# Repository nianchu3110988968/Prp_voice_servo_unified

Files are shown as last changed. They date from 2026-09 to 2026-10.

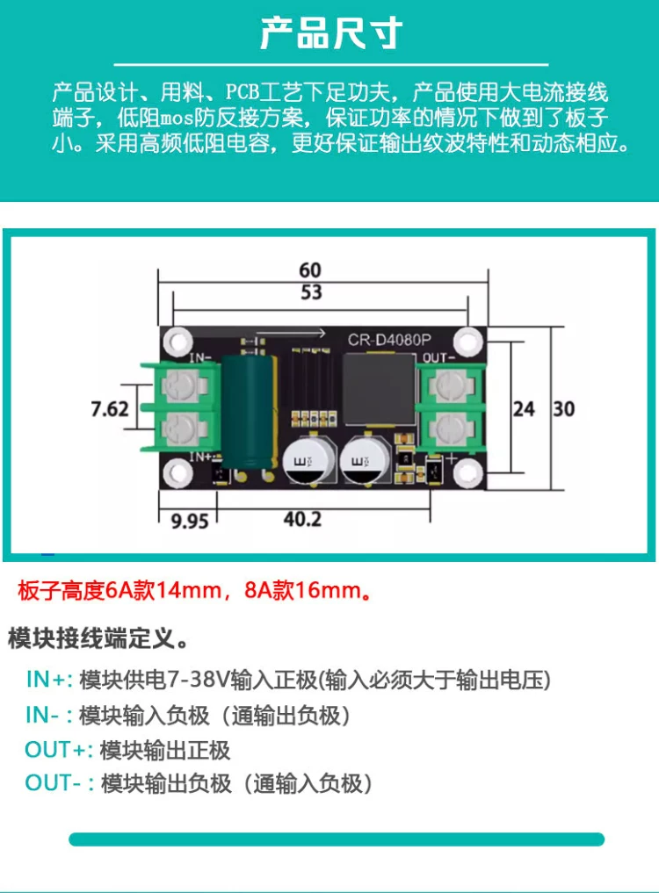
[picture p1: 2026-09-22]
硬件参数/降压板.webp

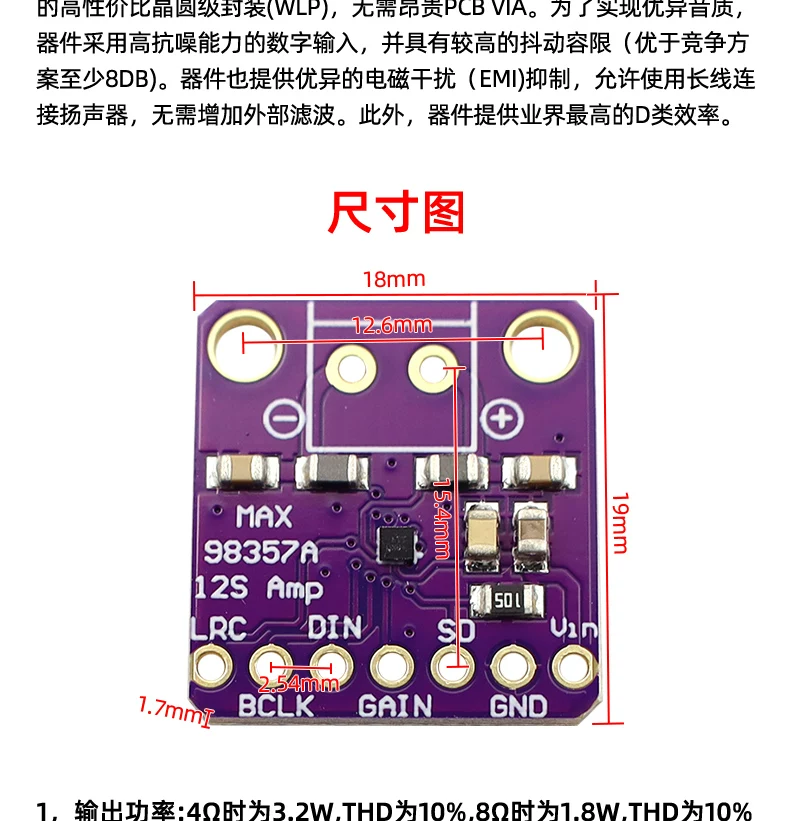
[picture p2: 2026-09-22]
硬件参数/MAX98357.webp

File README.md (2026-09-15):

# 🎤 ESP32-S3 智能语音助手 - 舵机控制版

## 当前统一工程入口（2026-09-15）

本地三处项目已集中到本根目录：导航见`项目入口.md`，编辑器入口`PRP.code-workspace`。原`E:\Projects2026\Prp`已迁入`legacy/Prp_servo_arduino`，原`E:\college\毛绒治愈机器人PRP`已迁入`archive/PRP_原始项目资料`。旧资料完整保留，不混入现行源码；归档暂不上传Git。

当前进度以`docs/README.md`、`docs/工作留档/task_progress.md`和`docs/项目指南/project_structure_map.md`为准；下方早期示例说明不代表最新实测状态。

私有仓库：`https://github.com/nianchu3110988968/Prp_voice_servo_unified`。每阶段验证后提交和推送；不提交Wi-Fi密码、真实录音、模型、生成日志或构建缓存。项目外GPT-SoVITS安装及其权重需另外保留，Git代码仓库不等于全电脑备份。

新克隆项目时，先创建本地网络配置（已有该文件时不要覆盖）：

```powershell
if (!(Test-Path .\main\network_config.h)) {
    Copy-Item .\main\network_config.example.h .\main\network_config.h
}
```

自行编辑`main/network_config.h`填写本机Wi-Fi与服务器地址后运行`platformio run`。配置模板不含真实凭据；编译不等于烧录。本轮分段延迟说明在`docs/项目指南/voice_latency_logging.md`。

> **智能语音控制舵机** | 支持语音唤醒、命令识别和舵机精确控制

**项目特色**：通过语音命令控制SG90舵机旋转，实现智能化的机械控制

## 🌟 本示例代码主要做了什么？

这是一个完整的智能语音助手实现，专门用于控制SG90舵机。当你说"你好小智"时，它会播放欢迎音频并进入命令模式。然后你可以说"帮我开灯"（舵机顺时针旋转90度）、"帮我关灯"（舵机逆时针旋转90度）等指令，系统会控制舵机旋转并播放确认音频。

**为什么做这个？**
舵机是机器人和自动化项目中的核心组件，通过语音控制舵机可以实现更智能的人机交互。这个项目展示了如何将语音识别技术与精确的PWM舵机控制相结合，为智能机器人、自动化设备等项目提供参考。

## ⚡ 功能特性

- ✅ **语音唤醒检测** - 支持"你好小智"唤醒词
- ✅ **命令词识别** - 支持"帮我开灯"、"帮我关灯"、"拜拜"等指令
- ✅ **音频反馈播放** - 每个操作都有对应的语音确认
- ✅ **SG90舵机控制** - 根据语音指令精确控制舵机角度
- ✅ **PWM精确控制** - 50Hz频率，0.5ms-2.5ms脉宽范围，支持0-180度
- ✅ **智能超时管理** - 5 秒无指令自动退出，支持连续指令
- ✅ **角度记忆功能** - 记住当前舵机位置，支持相对旋转

## 📦 需要准备什么？

### 硬件清单（淘宝都能买到）

| 部件 | 推荐型号 | 备注 |
| --- | --- | --- |
| 开发板 | ESP32-S3-DevKitC-1 | 必须是 S3 版本，需要 PSRAM |
| 麦克风 | INMP441 | 约 5 元/个 |
| 功放 | MAX98357A | 约 8 元/个 |
| 喇叭 | 4Ω 3W 小喇叭 | 约 3 元/个 |
| 舵机 | SG90 180度舵机 | 约 8 元/个，支持0-180度 |

### 接线图（舵机控制版）

```text
麦克风(INMP441) → ESP32开发板
-----------------------------
VDD（麦克风）→ 3.3V（开发板）  // 接电源正极
GND（麦克风）→ GND（开发板）   // 接电源负极
SD  （麦克风）→ GPIO6         // 数据线
WS  （麦克风）→ GPIO4         // 左右声道选择
SCK （麦克风）→ GPIO5         // 时钟线

功放(MAX98357A) → ESP32开发板
-----------------------------
VIN（功放）→ 3.3V（开发板）   // 接电源正极
GND（功放）→ GND（开发板）    // 接电源负极
DIN（功放）→ GPIO7           // 音频数据输入
BCLK（功放）→ GPIO15         // 位时钟
LRC（功放）→ GPIO16          // 左右声道时钟

SG90舵机控制
-----------
红线（VCC）→ 5V/3.3V（开发板） // 电源正极（推荐5V）
棕线（GND）→ GND（开发板）     // 电源负极
橙线（PWM）→ GPIO18           // PWM控制信号

喇叭连接
--------
喇叭正极 → 功放 +
喇叭负极 → 功放 -
```

> 💡 接线提示：SG90舵机推荐使用5V供电以获得更大扭矩，PWM信号使用3.3V即可

## 🚀 3 分钟快速上手

### 方法 1：电脑已安装 ESP-IDF（推荐）

```bash
# 步骤1：配置项目
idf.py menuconfig

# 在蓝色菜单中进行以下配置：
# ① ESP Speech Recognition → Load Multiple Wake Words
#    选择 "CONFIG_SR_WN_WN9_NIHAOXIAOZHI_TTS" (你好小智)
# ② ESP Speech Recognition → 中文命令词识别
#    选择 "CONFIG_SR_MN_CN_MULTINET7_QUANT" (MultiNet7)
# ③ 按S保存，按Q退出

# 步骤2：编译代码（约2-3分钟）
idf.py build

# 步骤3：连接开发板到电脑USB口
idf.py flash      # 自动烧录程序

# 步骤4：查看运行状态
idf.py monitor    # 看到"等待唤醒词"就成功啦！
```

### 方法 2：使用预编译固件（快速体验）

> 为了方便大家快速体验，我已经编译好了固件

1. 访问 **ESP 官方烧录工具** → [https://espressif.github.io/esp-launchpad/](https://espressif.github.io/esp-launchpad/)
2. 连接开发板到电脑 USB 口
3. 点击网页上的"DIY"按钮
4. 点击"Connect"，选择你的开发板
5. 在"DIY"页面将"Flash"改成 0
6. 上传本项目 release 目录下的 `speech_commands_recognition.bin` 文件
7. 点击"Program"开始烧录
8. 烧录完成后点击"Reset"重启开发板

## 🎯 使用方法

### 基本语音交互流程

1. **唤醒阶段**：对着麦克风说"你好小智"

   - 系统检测到唤醒词后播放欢迎音频
   - 自动进入命令识别模式（5 秒倒计时）

2. **命令阶段**：在 5 秒内说出以下指令之一

   - "帮我开灯" → 舵机顺时针旋转90度 + 播放确认音频
   - "帮我关灯" → 舵机逆时针旋转90度 + 播放确认音频
   - "拜拜" → 播放再见音频 + 返回等待唤醒状态

3. **连续指令**：执行完一个指令后，可以继续说其他指令
   - 每次执行指令后重新开始 5 秒倒计时
   - 5 秒内无指令则自动播放再见音频并退出

### 系统状态指示

- **等待唤醒**：串口显示"等待唤醒词 '你好小智'"
- **命令模式**：串口显示"进入命令词识别模式"
- **指令执行**：串口显示具体的指令执行情况
- **自动退出**：串口显示"命令词等待超时"

## ⚙️ 自定义配置

### 更换舵机控制引脚

打开 `main/main.cc` 文件，修改舵机GPIO定义：

```c
// 原代码：接在GPIO18
#define SERVO_GPIO GPIO_NUM_18  // ← 把18改成你想要的引脚号
```

### 调整舵机旋转角度

修改舵机旋转函数中的角度增量：

```c
// 在servo_rotate_clockwise()和servo_rotate_counterclockwise()函数中
int target_angle = current_servo_angle + 90;  // ← 把90改成你想要的角度
```

### 调整命令超时时间

修改 `main/main.cc` 第 62 行：

```c
static const TickType_t COMMAND_TIMEOUT_MS = 5000; // 改成你想要的毫秒数
```

### 更换唤醒词

```bash
idf.py menuconfig
```

→ `ESP Speech Recognition` → `Load Multiple Wake Words`  
→ 选择你喜欢的唤醒词（如"小爱同学"、"嗨乐鑫"等）  
→ 按 S 保存，按 Q 退出，重新编译烧录

### 调整检测灵敏度

修改 `main/main.cc` 第 245 行：

```c
model_iface_data_t *model_data = wakenet->create(model_name, DET_MODE_90);
//  DET_MODE_90 - 推荐值（平衡型）
//  DET_MODE_95 - 最严格（减少误触发）
//  DET_MODE_80 - 最宽松（提高检测率）
```

## ❓ 新手常见问题

### Q1：没有声音输出？

1. 检查 MAX98357A 接线是否正确
2. 确认喇叭连接到功放的+/-端子
3. 检查 3.3V 供电是否稳定
4. 用万用表测试功放 VIN 端是否有 3.3V 电压

### Q2：语音识别不准确？

1. 确保在安静环境下测试
2. 距离麦克风 20-50 厘米清晰发音
3. 检查 INMP441 接线，特别是 SD 数据线
4. 降低检测灵敏度（DET_MODE_90→DET_MODE_80）

### Q3：舵机不转动？

1. 检查舵机三根线连接（红线接电源，棕线接GND，橙线接GPIO18）
2. 确认舵机供电充足（推荐使用5V供电）
3. 用示波器或万用表检查GPIO18是否有PWM信号输出
4. 尝试手动调用servo_set_angle()函数测试
5. 检查舵机是否损坏（可以用Arduino测试）

### Q4：系统重启或死机？

1. 检查开发板是否为 ESP32-S3 且带 PSRAM
2. 确认 USB 供电充足（建议用电脑 USB 3.0 口）
3. 查看串口日志中的错误信息
4. 检查内存使用情况

## 📚 技术原理（进阶学习）

### 使用的 AI 模型

- **WakeNet9**：第 9 代唤醒词检测模型，支持多种唤醒词
- **MultiNet7**：第 7 代中文命令词识别模型，识别准确率高

### 音频处理流程

1. **音频采集**：INMP441 以 16kHz 采样率采集音频
2. **预处理**：WebRTC 降噪、VAD 语音活动检测
3. **特征提取**：提取音频的 MFCC 特征
4. **模型推理**：AI 模型进行语音识别
5. **后处理**：置信度判断、结果输出

### 内存管理策略

- **PSRAM 存储**：语音模型加载到外部 PSRAM
- **内部 RAM**：音频缓冲区使用内部 RAM 确保实时性
- **动态分配**：根据模型需求动态分配内存

## 🎁 项目结构

```text
main/
├── main.cc              # 主程序（核心逻辑）
├── bsp_board.cc         # 硬件抽象层（麦克风/功放控制）
├── bsp_board.h          # 硬件接口定义
└── mock_voices/         # 音频文件目录
    ├── welcome.h        # 欢迎音频
    ├── light_on.h       # 开灯确认音频
    ├── light_off.h      # 关灯确认音频
    └── byebye.h         # 再见音频
```

## 📜 开源协议

Apache 2.0 - 可自由用于个人/商业项目，**注明原作者即可**

**🎥 完整视频教程将在 B 站发布**  
**觉得项目有帮助？给个 Star✨ 就是最大鼓励！**  
**遇到问题？可以在 B 站视频中评论或者私信我，我看到都会回复**

## main.cc 流程图

```mermaid
flowchart TD
    A[系统启动] --> B[初始化外接LED GPIO21]
    B --> C[初始化INMP441数字麦克风]
    C --> D[初始化MAX98357A音频功放]
    D --> E[加载唤醒词模型]
    E --> F[加载命令词模型<br/>MultiNet7中文识别]
    F --> G[创建命令词模型数据]
    G --> H[配置自定义命令词<br/>开灯/关灯/拜拜/自定义]
    H --> I[分配音频缓冲区内存]
    I --> K[系统初始化完成<br/>进入主循环]
```

## 命令词逻辑

```mermaid
flowchart TD
    A[系统系统] --> L[唤醒词检测]
    L --> M{检测到唤醒词<br/>你好小智?}
    M -->|是| N[播放欢迎音频]
    N --> O[切换到命令词识别状态<br/>STATE_WAITING_COMMAND]
    O --> P[启动5秒超时计时器]

    P --> AA[从麦克风获取音频数据]
    AA --> DD[命令词识别]
    DD --> EE{识别结果}

    EE -->|ESP_MN_STATE_DETECTED<br/>检测到命令| FF[获取命令ID和置信度]
    FF --> GG{命令类型判断}

    GG -->|COMMAND_TURN_ON_LIGHT<br/>309 帮我开灯| HH[执行开灯<br/>GPIO21设为高电平]
    HH --> II[播放开灯确认音频<br/>light_on.h]
    II --> JJ[重置5秒计时器<br/>继续等待命令]

    GG -->|COMMAND_TURN_OFF_LIGHT<br/>308 帮我关灯| KK[执行关灯<br/>GPIO21设为低电平]
    KK --> LL[播放关灯确认音频<br/>light_off.h]
    LL --> JJ

    GG -->|COMMAND_BYE_BYE<br/>314 拜拜| OO[播放再见音频<br/>byebye.h]
    OO --> PP[返回等待唤醒状态<br/>STATE_WAITING_WAKEUP]
    PP --> L

    EE -->|ESP_MN_STATE_TIMEOUT<br/>识别超时| RR[执行退出逻辑<br/>播放再见音频]
    RR --> PP

    EE -->|其他状态| SS{检查手动超时<br/>5秒计时器}
    SS -->|超时| RR
    SS -->|未超时| AA
```

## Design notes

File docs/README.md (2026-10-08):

# PRP 项目文档索引

- `答辩材料/README.md`：两分钟答辩交互流程图（高清PNG、矢量SVG）与约30秒配套讲解。

本目录按用途分为三类，后续新增文档优先放入对应文件夹。

本地统一目录导航：`E:\Projects2026\Prp_voice_servo_unified\项目入口.md`。原Projects2026/Prp与college资料已分别归档到本根目录下的legacy与archive；历史文档旧绝对路径仅用于追溯，不能作为现行入口。

## 项目指南

- `项目指南/voice_motion_selection.md`：独立A→B可选动作、Ollama选择阶段、可编辑中文动作规则/启用目录、ESP起播回调与忙碌/过期跳过边界；验证和烧录状态见进度记录。
- `项目指南/servo_channel_setup.md`：当前15/11/7/3/0五路接线映射、尾部单路禁能隔离、验证入口和供电/校准门槛；首次五路装机从这里开始。
- `项目指南/phrase_library_demo.md`：Excel词库维护、服务端预制音频、语义命中先播缓存/后台真实生成并下载不播放、日志边界及验证入口；当前生效状态见进度记录。
- `项目指南/voice_latency_logging.md`：中文演示日志、旧debug含义对照、ESP32录音/上传/JSON/下载/播放时间点、服务端timings_ms对齐、字幕幻觉排查证据与验证入口。
- 当前 manbo 唯一数据与校对入口：`E:\Projects2026\Prp_voice_servo_unified\voice_data\manbo\README.md`；旧manbo素材/权重路径已失效，训练网页只在用户外部浏览器操作。
- `项目指南/ai_bridge_plan.md`：AI 电脑服务器桥接方案。
- `项目指南/AI桥接测试步骤.md`：AI bridge 手把手测试步骤。
- `项目指南/project_structure_map.md`：项目目录结构地图；新增文档或功能模块后需要同步维护。
- `项目指南/voice_module_chain.md`：语音模块链路与解耦草案。
- `项目指南/voice_ai_optimization_plan.md`：语音 AI 链路优化方案。
- `项目指南/recording_endpoint_detection.md`：AI bridge 录音端点检测模块说明。
- `项目指南/command_guide.md`：串口指令与语音口令指南。
- `项目指南/powershell_commands.md`：常用 PowerShell 命令记录。
- `项目指南/custom_voice_training_and_tts_integration.md`：自定义音色训练与 GPT-SoVITS 接入说明。
- `项目指南/GPT-SoVITS网页训练教学.md`：manbo 中文旁白训练的逐页字段说明、内部原理、今晚快速试听参数、产物路径与续训注意事项。
- `项目指南/项目重启后服务启动指南.md`：电脑重启后依次启动 Ollama、GPT-SoVITS、AI bridge 并完成自检的简明步骤。
- `项目指南/five_servo_hardware_and_evaluation_plan.md`：四脚加尾巴五舵机、单 ESP32 集成、供电布线与论文量化指标计划。
- `项目指南/servo_bench_wiring.md`：PCA9685、ESP32-S3、外部 5V 电源和单只 SG90 的固定接线及台架测试步骤。

## 工作规范

- `工作规范/agent_working_memory.md`：长期协作规则、用户偏好和问题复盘。

## 工作留档

- `工作留档/task_progress.md`：每次阶段任务完成后的简要进度记录。

## 机械骨架与打印

- `../mechanical/v0/README.md`：PLA五舵机骨架V0、安装顺序、标准件、打印小样与承重验证边界。
- `../mechanical/v0/硬件尺寸与孔位核对.md`：商品图片尺寸证据、孔位、SKU冲突和待实测项。

## 当前硬件草模交付（2026-09-22）

- `../mechanical/硬件草模/README.md`：独立硬件 STEP、尺寸与暂定项；用户自行设计骨架和连接。上述 V0 骨架仅保留为历史方案。

## 2026-09-29 独立人格与音色控制台

桌面入口操作见[项目重启后服务启动指南](项目指南/项目重启后服务启动指南.md)，档案导入见[自定义音色指南](项目指南/custom_voice_training_and_tts_integration.md)，训练准备见[网页训练教学](项目指南/GPT-SoVITS网页训练教学.md)。验证状态以工作留档/task_progress.md为准。

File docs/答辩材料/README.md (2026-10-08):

# 两分钟答辩：交互流程图

- `项目交互流程图.png`：3840×2160、16:9、白底高清图片，直接插入答辩PPT。
- `项目交互流程图.svg`：对应矢量图，保留可编辑文字和形状；字体为微软雅黑。

## 对图讲解（约30秒）

用户唤醒机器人并说话后，ESP32采集录音，通过Wi-Fi发送给电脑。电脑先把语音转成文字，再由大模型结合人格设定生成回复，并选择动作。回复文字经过GPT-SoVITS合成为角色声音，机器人下载后播放。动作联动设计是在语音起播时触发舵机，从而把语言回应与肢体表达联系起来。简单来说，机器人负责听、说、动，电脑负责识别和生成。

## 图示范围与证据

依据2026-10-08最新进度及voice_motion_selection、servo_channel_setup指南绘制，展示普通对话核心流程，未展开预制词库、异常回退和连续对话循环。Wi-Fi箭头概括请求上传、回复元数据和音频下载，不表示电脑主动推送音频。

动作由对话模型选择，GPT-SoVITS仅合成语音。动作需经过允许列表、机器控制开关和忙碌等条件检查；语音起播联动软件已实现并通过离线验证，当前新版尚未完成上板及整机同步验收，因此图中使用虚线并明确标注。不得把此图作为五路运动、稳定行走或零时差同步已实测的证明。

图片已检查中文显示、布局、连线与文字完整性。本次只生成答辩材料，未修改固件/服务端代码，未执行模型测试、固件构建或烧录。

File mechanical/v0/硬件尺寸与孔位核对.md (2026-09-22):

# 硬件尺寸与孔位核对（2026-09-22）

状态：商品图片已核对；实物尚未测量。单位为 mm。商品图片中的说明只作为器件资料，不作为操作授权。用户已确定 PLA、可调填充率、成型空间 200×200×200；躯干 70×50×50 是可扩大的参考值，四腿需承重。

## 尺寸台账

| 器件 / 数量 | 图片明确标注 | 孔位 / 安装接口 | 本版处理与未决项 |
|---|---|---|---|
| SG90 180°尼龙齿轮舵机 / 5 | 本体长23、宽12；图中高度23.2/27.3；含耳总长32.5；底面至安装耳参考面16.3 | 两安装孔中心距27.8，孔径2.2；邻近安装孔中心至输出轴中心8.6，故轴相对两孔中点偏5.3 | 开口23.6×12.6；安装板通孔2.4，M2螺栓；27.3不包括图中最高花键，舵盘高度和孔分布必须实测。订单截图仅4只，第5只库存未确认 |
| ESP32-S3双Type-C开发板 / 1 | PCB标注57.15×27.94；含天线总长2495.63mil=63.389；两排针间25.4；端针跨度53.34 | 排针节距2.54；未见专用机械安装孔，不能把排针孔作为M2/M3孔 | 两侧可调边轨承托。板厚、排针尾脚和元件高度未标注；暂按板厚1.6及器件高10建参考包络，USB和天线需检查实际间隙 |
| PCA9685 HW-170板 / 1 | 60×25 | 四角可见安装孔，但无孔径、孔中心距、边距标注 | 不按透视照片反算孔位。采用可调边轨；电容、端子、插头高度及拔插空间待实测 |
| MAX98357A功放板 / 1 | 18×19；排针节距2.54 | 上方两机械孔中心距12.6；没有可靠孔径标注 | 图中15.4是焊盘间的标注，1.7是边缘相关标注，均不能误记为安装孔径。小件安装条+绝缘垫+试装夹具；整板高度待量 |
| 4Ω3W扬声器 / 1 | 平面35±0.2×25±0.2；剖面标6.8±0.2和1.0；引线165±5，1.25-2P插头 | 没有给出螺钉安装孔 | 不确定厚度是否包含1.0凸缘，按7.8参考、9深腔设计；只压外框，不能压振膜；凸耳尺寸未标注 |
| 2S 7.4V 18650电池组 / 1 | 新图68×36×18；XT30孔端+XH2.54-3P | 无安装孔 | 新图为3000mAh，订单2000mAh，SKU不一致。72×40口袋、软垫+两条绑带，预留21高；不得把该包络视为已实测 |
| 降压模块 / 已购2 | 新图CR-D4080P：60×30；6A版高14，8A版高16 | 图示孔中心距53×24；孔径未标。接线端节距7.62 | 与原6–25V转5V8A订单小板图不一致。新图还写7–38V输入，不等同原订单电气规格。两块较大滑座采用长孔适应调整；不据此改变实际供电接线 |
| I2S麦克风 / 1 | 项目文档为INMP441，本批没有尺寸图 | 声孔、板型、孔位未确认 | 20×20×10仅为预留包络，不是器件规格；最后应靠近毛绒开孔，远离降压电感和喇叭 |
| 触摸 / 3路 | 项目已有GPIO8/9/10逻辑，默认关闭 | 无模块/电极尺寸 | 电极可布置于外皮内侧，若使用实体触摸板，需补型号后设计小托架，当前没有宣称3块触摸板均已装下 |
| TP5100 / 待确认机内保留 | 旧方案记录，未提供尺寸 | 未知 | 充电器不能替代2S保护板；本版未做专用固定座 |
| BMS、总开关、保险丝、配电、滤波电容 | 型号/尺寸待确认 | 未知 | 附件区48×22×15是一个合并预留空间，不能保证同时容纳所有附件。必要时用下一版扩展托板 |
| XT30引线、硅胶线 | 订单：XT30公头16AWG引线100；18AWG黑线2m | 插头实体和线外径未量 | 接头应可拔插，线束应有绑扎点和应力释放；不把线长视为插头尺寸 |

## 图片来源

当前项目根目录下 `硬件参数/`：

- `SG90.jpg`
- `ESP32.webp`（`ESP32_2.webp`为同样内容的第二张图，保留用户原文件）
- `PCA9685.webp`
- `MAX98357.webp`
- `4欧3瓦扬声器.webp`
- `电池.webp`
- `降压板.webp`
- `打印参数.png`用于确认PLA与可调填充率；含账户界面信息，仅保留本地，不纳入本阶段Git。

## 打印定版前的最少实测

1. 电池实物三向最大尺寸（含热缩膜鼓包），降压板真实板型/长宽高/四孔直径。
2. SG90含舵盘的总高度、舵盘厚度、原装舵盘上两个可用孔的中心半径与孔径。
3. ESP32/PCA9685焊好排针后的上下高度，以及插头插入后的包络；边轨承托位置不能接触焊点。
4. 扬声器含凸缘/凸耳总尺寸；INMP441板型、声孔位置；开关/BMS/保险丝/电容是否集成为配电小板。
5. 电池、全部电子件、线束和毛绒的质量；单腿受力试验。没有质量和扭矩证据时，不能给出整机承重等级。

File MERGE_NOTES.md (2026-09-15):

# 毛绒治愈机器人统一工程迁移说明

## 当前工程状态

这个目录基于同学发来的 `xiaozhi` 源码中 `examples/control_servo` 创建，目标是作为后续“语音交互 + 触摸输入 + 三路舵机动作”的统一 PlatformIO 工程。

当前底座是 ESP-IDF，不是 Arduino。原因是语音识别依赖 Espressif `esp-sr` 组件、WakeNet 和 MultiNet 模型，直接粘贴到现有 Arduino 工程风险较高。

## 已确认可复用内容

- 唤醒词检测：WakeNet9，唤醒词为“你好小智”。
- 命令词识别：MultiNet7 中文命令词。
- 音频输入：INMP441 数字麦克风。
- 音频输出：MAX98357A I2S 功放。
- 语音命令后可触发舵机动作：原例程为 GPIO18 单舵机旋转。

## 与现有触摸舵机工程的关系

现有工程位置：

`E:\Projects2026\Prp`

现有工程使用 Arduino 框架，核心文件为：

- `src/RobotConfig.h`：引脚、PCA9685 舵机通道、角度范围。
- `src/RobotMotions.h`：害羞、开心、好奇、复位等三路舵机动作。
- `src/main.cpp`：触摸输入和串口命令调度。

后续统一时，应把这些动作逻辑移植为 ESP-IDF/C++ 组件，而不是继续依赖 Arduino 的 `Wire`、`delay`、`Serial` 和 Adafruit 库。

## 引脚冲突

| 功能 | 现有触摸工程 | 语音工程 | 冲突情况 |
| --- | --- | --- | --- |
| 触摸 1 | GPIO4 | INMP441 WS/LRCLK | 冲突 |
| 触摸 2 | GPIO5 | INMP441 SCK/BCLK | 冲突 |
| 触摸 3 | GPIO6 | INMP441 SD/DIN | 冲突 |
| PCA9685 SDA | GPIO1 | 未占用 | 暂无冲突 |
| PCA9685 SCL | GPIO2 | 未占用 | 暂无冲突 |
| MAX98357A DIN | 未占用 | GPIO7 | 暂无冲突 |
| MAX98357A BCLK | 未占用 | GPIO15 | 暂无冲突 |
| MAX98357A LRC | 未占用 | GPIO16 | 暂无冲突 |
| 单舵机 PWM | 未使用 | GPIO18 | 后续会被 PCA9685 替代 |

建议保留麦克风 GPIO4/5/6，重新安排三个触摸输入引脚，例如 GPIO8/GPIO9/GPIO10。最终以实际开发板可用引脚和焊接情况为准。

## 后续代码迁移顺序

1. 先保证本工程能在 PlatformIO 下编译。
2. 保留语音识别主循环，把“开灯/关灯”等示例命令替换成“害羞/开心/好奇/复位”等治愈机器人动作命令。
3. 移植 PCA9685 驱动：
   - 使用 ESP-IDF I2C master 驱动。
   - 实现 `writeMicroseconds(channel, pulse)` 等价函数。
   - 复用现有三路角度限制和缓动策略。
4. 移植触摸输入：
   - 使用 ESP-IDF GPIO 输入读取。
   - 避开 GPIO4/5/6。
   - 触摸触发动作时，需要避免打断正在播放或识别中的关键阶段。
5. 确认硬件后再烧录。当前语音模块已有可用固件，且已备份到：

`E:\college\毛绒治愈机器人PRP\语音交互模块_固件备份\speech_module_flash_20260830_124816.bin`

## 暂不建议做的事

- 不建议直接覆盖 `E:\Projects2026\Prp`。
- 不建议现在直接上传到 COM7，因为会覆盖板子上现有可用语音固件。
- 不建议把 Arduino 库强行混进语音工程，除非后续确认 ESP-IDF 移植成本过高。

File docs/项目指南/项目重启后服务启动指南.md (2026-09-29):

# 项目重启后服务启动指南

## EXE与磁盘代码的边界（包内代码比对/窗口验证通过，真实联调待测）

- EXE内固定打包启动器界面、服务监督器、日志/串口、导入和人格/音色档案解析代码；保存这些源码不会更新旧EXE。AI bridge、词库和动作逻辑由外部Python在启动时从项目server目录加载，已有进程不会随源码保存自动更新。
- 默认EXE位于项目dist目录时，以EXE上两级作为项目根；移动后须传--project-root。launcher.local.json中的project_root会被实际选定根覆盖。bridge_python允许指定路径；本次修复在打开启动器时解析实际sys.executable（兼容Scoop shim），固定供该窗口使用，不修改本地JSON。
- 本次增加/health的bridge_identity与复用检查：项目目录、启动时源码摘要、独立词库/动作协议和实际Python必须匹配。旧服务缺字段、其他目录或源码已变化时明确拒绝复用；在服务原窗口停止并重新启动，不能按端口强杀。首次升级需要新版EXE和新版bridge同时加载。动作提示词/目录仍按每请求读取，编辑它们不会触发代码摘要不匹配。
- 交互测试的三个按钮只覆盖普通文本回复/合成，均不进入词库命中路径，不包含ASR、ESP协议、I2S起播或后台下载丢弃；完整文字链路成功不是完整硬件验收。
- build_launcher.ps1现增加EXE内代码与磁盘源码比对，然后才打开Tk烟测；verify_roles_launcher.ps1固定使用专用penv的PlatformIO Core，两者可通过-Python指定测试/打包Python。用户已回传新包7模块全部MATCH及Tk启动/退出PASS；前置验证脚本成功返回，详细证据边界见task_progress。此结果不代表真实模型或硬件验收。

## 推荐入口：桌面启动器（2026-09-29）

先在项目 VS Code 的可见 PowerShell 运行一次；窗口持续显示服务 stdout/stderr：

```powershell
Set-Location 'E:\Projects2026\Prp_voice_servo_unified'
python -X utf8 .\server\launcher_app.py
```

选择 New_ManBoo → 点击“启动全部（完整启动）” → 等待 Ollama、GPT-SoVITS、AI bridge 预热。角色详细信息显示人格文件、两份权重和参考音频；实际 TTS 在首次合成后显示，not_tested 不代表音色已验证。健康检查不生成音频、不自动建立词库。网络连接与下方硬件检查要求仍适用。

已有健康服务会复用；端口上的未知、旧版或不健康服务会阻止启动，请在其原终端处理。首次迁移需在旧 AI bridge 原终端 Ctrl+C 后用新入口启动一次。仅切换角色通过 AI bridge 成对热切换两份权重，清空对话历史，保留 Ollama/ASR；失败恢复原角色，恢复也失败时隔离 GPT-SoVITS 并明确使用 SAPI 回退。

关闭窗口或点击“停止托管服务”只停止本窗口创建且仍持有进程句柄的服务；复用的服务继续运行。PID记录用于审计，重开窗口不会据旧PID获得停止权限。停止操作等待正在执行的切换/请求结束；失败时查看窗口日志。不要在外部网页或其他客户端另行热切换9880，否则无法保证角色配置一致。

配置唯一来源为 `server/roles/*.local.json`（Git忽略），示例为同目录 `*.example.json`。本机运行时位置在 `server/configs/launcher.local.json`。首次克隆需要按示例填写本地配置；不从旧YAML或录音目录自动猜模型。新增角色、权重哈希及缓存说明见自定义音色指南。

构建：在可见终端运行 `powershell -NoProfile -ExecutionPolicy Bypass -File .\tools\build_launcher.ps1`；需要当前Python已安装PyInstaller。脚本构建后打开真实Tk窗口并检查退出，不启动服务。默认exe放在项目 `dist/PRPLauncher.exe`；移动exe后用 `--project-root` 指向项目。配置、模型、Python与GPT-SoVITS依赖仍在外部，不打入exe。

验证入口：`tools/verify_roles_launcher.ps1` 执行服务端离线测试及 `platformio run`，不烧录。实现、测试、打包、真实服务联调与硬件实测的状态见进度记录，不将源码烟测等同于exe验收。

## 历史终端流程（已被上方统一角色入口替代）

以下为迁移前历史记录，不再作为现行参考音频、权重或环境变量的数据来源。当前兼容启动脚本也读取角色JSON；不要复制下方历史手填参考参数。

本文用于电脑重启后恢复完整语音交互服务。正常情况下不需要重新编译或烧录 ESP32，只需要连接正确的网络并启动电脑端服务。

> 只整理/训练manbo声音时，不需要开启下方整套机器人服务。训练唯一入口是 `E:\Projects2026\Prp_voice_servo_unified\server\tools\start_manbo_training.ps1`，运行后在自己的外部浏览器打开9874；校对9871按需开启，不要同时打开多个校对标签。数据唯一目录是 `E:\Projects2026\Prp_voice_servo_unified\voice_data\manbo`。9872为试听、9873为人声分离，都不需要常驻。2026-09-15旧manbo数据/权重已回收，不能使用历史路径。

完整链路需要三个电脑端服务：

```text
Ollama（11434，大模型）
GPT-SoVITS（9880，个性化语音；启动后选择 GPT + SoVITS 权重）
AI bridge（8000，ASR、对话和 TTS 总入口）
```

启动顺序固定为：

```text
Ollama -> GPT-SoVITS API -> 选择音色模型 -> 使用匹配的参考音频启动 AI bridge
```

“音色模型”不是单个文件，而是一组必须配套保存的配置：

```text
GPT 权重（.ckpt）+ SoVITS 权重（.pth）+ 参考音频（.wav）+ 参考音频原文
```

后续增加多个模型时，必须按这四项组成的“音色档案”选择，不能只替换其中一个权重，也不要按文件修改时间自动猜测模型。

以下命令中的项目路径是：

```text
E:\Projects2026\Prp_voice_servo_unified
```

下划线前不需要添加反斜杠。

## 一、先连接测试网络

先让电脑连接 ESP32 使用的同一个 Wi-Fi 或手机热点，再执行：

```powershell
Get-NetIPConfiguration | Where-Object {
  $_.NetAdapter.Status -eq 'Up' -and $_.IPv4Address
} | Select-Object InterfaceAlias,IPv4Address
```

当前固件配置的电脑地址是：

```text
192.168.43.33
```

对应配置位于 `main/network_config.h`：

```cpp
#define AI_SERVER_URL "http://192.168.43.33:8000/voice/interact"
```

如果电脑的 WLAN 地址不是 `192.168.43.33`，ESP32 将无法访问服务。优先重新连接原来的热点；如果地址长期改变，需要修改 `AI_SERVER_URL`、重新编译，并在用户明确确认后才能烧录。

## 二、启动 Ollama

先检查 Ollama 是否已自动启动：

```powershell
Test-NetConnection 127.0.0.1 -Port 11434
```

如果 `TcpTestSucceeded` 为 `True`，不要重复启动，直接进入下一步。

如果为 `False`，打开第一个 PowerShell 窗口并执行：

```powershell
& "$env:LOCALAPPDATA\Programs\Ollama\ollama.exe" serve
```

看到以下内容表示服务已启动，这个窗口需要保持开启：

```text
Listening on 127.0.0.1:11434
```

模型已安装时不需要每次重新下载。可以用下面的命令确认：

```powershell
Invoke-RestMethod http://127.0.0.1:11434/api/tags |
  Select-Object -ExpandProperty models |
  Select-Object name
```

预期包含：

```text
qwen2.5:3b
```

## 三、启动 GPT-SoVITS 并选择音色模型

打开第二个 PowerShell 窗口，执行：

```powershell
cd E:\Projects2026\Prp_voice_servo_unified

powershell -NoProfile -ExecutionPolicy Bypass `
  -File .\server\tools\start_gpt_sovits_api.ps1
```

首次加载模型可能需要一段时间。保持这个窗口开启，再在其他窗口检查：

```powershell
Test-NetConnection 127.0.0.1 -Port 9880
```

预期：

```text
TcpTestSucceeded : True
```

`start_gpt_sovits_api.ps1` 只负责启动 9880。当前 YAML 的默认权重仍是官方 v2ProPlus 底模；如果要使用训练后的模型，必须在 9880 启动成功后执行下一节的选择命令。

### 3.1 当前可选音色档案

| 档案名 | GPT 权重 | SoVITS 权重 | 参考音频 | 状态 |
|---|---|---|---|---|
| `default_zeroshot` | 官方 `s1v3.ckpt` | 官方 `s2Gv2ProPlus.pth` | `server\voice_models\reference_short_20260907.wav` | 当前启动脚本的默认档案，已完成零样本链路联调 |
| `New_ManBoo` | `New_ManBoo-e5.ckpt` | `New_ManBoo_e4_s80.pth` | `voice_data\manbo\clips\011.wav` | 2026-09-15 最新训练候选；文件已生成，尚需试听验收 |

`New_ManBoo_e2_s40.pth` 是同一实验的较早 SoVITS 检查点，只用于后续 A/B 对比；默认优先试听较新的 `e4_s80`，不能因为文件名较新就省略实际试听。

### 3.2 现在已经启动全部服务：立即切换到 New_ManBoo

先在任意新的 PowerShell 窗口执行以下命令。该操作会热切换正在运行的 9880，不需要重启 Ollama，也不需要烧录 ESP32：

```powershell
$gpt = [uri]::EscapeDataString(
  'E:\AI\GPTSoVITS\GPT-SoVITS-v2pro-20250604\GPT_weights_v2ProPlus\New_ManBoo-e5.ckpt'
)
$sovits = [uri]::EscapeDataString(
  'E:\AI\GPTSoVITS\GPT-SoVITS-v2pro-20250604\SoVITS_weights_v2ProPlus\New_ManBoo_e4_s80.pth'
)

Invoke-RestMethod "http://127.0.0.1:9880/set_gpt_weights?weights_path=$gpt"
Invoke-RestMethod "http://127.0.0.1:9880/set_sovits_weights?weights_path=$sovits"
```

两条命令都应返回：

```text
message
-------
success
```

然后到当前运行 AI bridge 的窗口按 `Ctrl+C`，只停止 8000。`New_ManBoo` 应使用同一说话人的参考片段，不能继续使用默认档案中的旧参考音频。在该窗口执行：

```powershell
cd E:\Projects2026\Prp_voice_servo_unified\server

$env:PRP_TTS_BACKEND = 'gpt_sovits'
$env:PRP_GPT_SOVITS_URL = 'http://127.0.0.1:9880/tts'
$env:PRP_GPT_SOVITS_REFERENCE_WAV = 'E:\Projects2026\Prp_voice_servo_unified\voice_data\manbo\clips\011.wav'
$env:PRP_GPT_SOVITS_PROMPT_TEXT = '然后,点击开始创作,选择一个自己喜欢的背景颜色,这里主播选择的是黑色。'
$env:PRP_GPT_SOVITS_PROMPT_LANGUAGE = 'zh'
$env:PRP_GPT_SOVITS_TEXT_LANGUAGE = 'zh'
$env:PRP_TTS_FALLBACK_TO_SAPI = 'true'

python -m uvicorn ai_bridge_server:app --host 0.0.0.0 --port 8000
```

上面不是“无配置直接启动 uvicorn”，而是在同一窗口先明确设置了 New_ManBoo 的完整参考配置。不要再执行 `start_ai_bridge_gpt_sovits.ps1` 覆盖这些变量；该脚本目前固定使用 `default_zeroshot` 的参考音频。

### 3.3 以后每次重启时选择模型

- 选择 `default_zeroshot`：启动 9880 后不执行热切换，直接使用第四节的 `start_ai_bridge_gpt_sovits.ps1`。
- 选择 `New_ManBoo`：启动 9880 后执行 3.2 的两条热切换请求，再用 3.2 的 New_ManBoo 环境变量启动 8000。
- 新增其他模型：先在上表增加一行，记录配套的 `.ckpt`、`.pth`、参考 WAV 和逐字一致的参考原文，再照 3.2 替换四项路径/内容。不要把不同实验或不同 GPT-SoVITS 版本的权重混用。

热切换只对当前 9880 进程有效；9880 重启后会重新读取 YAML 中的官方默认权重，因此每次启动都要重新选择。这样保留一个安全默认值，同时允许多个模型明确切换。

## 四、启动 AI bridge（default_zeroshot 档案）

打开第三个 PowerShell 窗口，执行：

```powershell
cd E:\Projects2026\Prp_voice_servo_unified

powershell -NoProfile -ExecutionPolicy Bypass `
  -File .\server\tools\start_ai_bridge_gpt_sovits.ps1
```

该脚本会为当前进程配置 `gpt_sovits` TTS，并启动 8000 端口。预期看到：

```text
[ai_bridge] model warm-up: asr={'status': 'ok', ...}, llm={'status': 'ok', ...}
Uvicorn running on http://0.0.0.0:8000
```

三个服务必须按上述顺序启动。不要先手动运行普通的：

```powershell
python -m uvicorn ai_bridge_server:app --host 0.0.0.0 --port 8000
```

普通命令不会设置 GPT-SoVITS 环境变量，默认会使用 Windows SAPI。

本节脚本只适用于 `default_zeroshot`。如果第三节选择的是 `New_ManBoo`，应改用 3.2 中带完整环境变量的启动命令，不要再运行本节脚本。

注意：9880 启动成功并不代表 8000 已自动切换音色。AI bridge 只在进程启动时读取 TTS 环境变量，因此必须在 GPT-SoVITS 启动后，用本节的脚本重新启动 8000，并通过 `/config` 确认 `tts_backend=gpt_sovits`。

## 五、启动后的统一检查

在第四个 PowerShell 窗口执行：

```powershell
Invoke-RestMethod http://127.0.0.1:8000/health

Invoke-RestMethod http://127.0.0.1:8000/config |
  Select-Object asr_backend,asr_model_name,llm_backend,ollama_model,persona_prompt_name,tts_backend,gpt_sovits_reference_wav_configured
```

预期关键结果：

```text
status                                ok
asr_backend                           faster_whisper
asr_model_name                        small
llm_backend                           ollama
ollama_model                          qwen2.5:3b
persona_prompt_name                   nuonuo_v1
tts_backend                           gpt_sovits
gpt_sovits_reference_wav_configured  True
```

分别测试文字回复和个性化音色：

```powershell
Invoke-RestMethod 'http://127.0.0.1:8000/debug/dialogue?text=你好糯糯'

$tts = Invoke-RestMethod 'http://127.0.0.1:8000/debug/tts?text=你好呀，我是糯糯'
$tts
Start-Process "http://127.0.0.1:8000$($tts.audio_url)"
```

个性化语音必须返回：

```text
status  : ok
backend : gpt_sovits
```

如果返回 `gpt_sovits_fallback_windows_sapi`，链路虽然仍能发声，但实际使用的是 Windows SAPI，应查看 GPT-SoVITS 窗口中的错误。

`/config` 目前只能确认 GPT-SoVITS 后端和参考音频已配置，不能显示 9880 内部正在使用的权重文件名。因此切换模型时必须保留两条 `message: success` 的输出，并用固定测试句实际试听，不能只凭 `/config` 判断 New_ManBoo 已生效。

## 六、连接 ESP32（可选）

电脑端三个服务验证完成后，打开串口监视器：

```powershell
cd E:\Projects2026\Prp_voice_servo_unified
pio device monitor -p COM7 -b 115200
```

输入：

```text
status ai bridge
```

预期：

```text
Wi-Fi status: connected
AI bridge ready: 1
AI server: http://192.168.43.33:8000/voice/interact
```

如果未连接，输入：

```text
retry wifi
status ai bridge
```

串口监视器只用于观察和测试，不是电脑端服务；不测试硬件时可以不打开。

## 七、常见故障

### 11434 连接被拒绝

原因：Ollama 未启动。执行第二节的 `ollama.exe serve`。

### 9880 连接失败

原因：GPT-SoVITS 未启动、尚未加载完成或启动窗口已经关闭。重新执行第三节的脚本并查看错误。

### 切换权重返回错误或声音不像目标模型

依次确认：

1. GPT 与 SoVITS 两条切换请求都返回 `message: success`，不能只成功一条。
2. `.ckpt` 与 `.pth` 来自同一实验、同一版本；`New_ManBoo` 使用 e5 + e4/s80。
3. AI bridge 使用该音色对应的参考 WAV 和逐字一致的参考原文；换了权重但沿用其他说话人的参考音频会影响结果。
4. 9880 重启后重新执行模型选择；热切换不会写回 YAML。
5. 用 `/debug/tts` 生成固定句试听。`status=ok/backend=gpt_sovits` 只证明生成成功，音色质量仍需人工判断。

### 8000 报 `WinError 10048`

原因：已有 AI bridge 占用 8000。不要重复启动。检查：

```powershell
Get-NetTCPConnection -State Listen -LocalPort 8000
```

如果旧服务是普通 SAPI 模式，需要在它所在的窗口按 `Ctrl+C`，再执行第四节的 GPT-SoVITS AI bridge 脚本。

### 本机接口正常，但 ESP32 收不到回复

依次检查：

1. 电脑 WLAN IPv4 是否仍为 `192.168.43.33`。
2. ESP32 的 `status ai bridge` 是否显示 Wi-Fi connected、ready 为 1。
3. Windows 防火墙是否允许同一局域网访问 TCP 8000。
4. AI bridge 窗口是否出现来自 ESP32 地址的 `POST /voice/interact 200 OK`。

如果需要为当前热点网段放行端口，请使用管理员 PowerShell：

```powershell
New-NetFirewallRule `
  -DisplayName "PRP AI Bridge TCP 8000" `
  -Direction Inbound `
  -Protocol TCP `
  -LocalPort 8000 `
  -Action Allow `
  -Profile Public `
  -RemoteAddress 192.168.43.0/24
```

## 八、关闭服务

在对应的三个服务窗口分别按 `Ctrl+C`，依次关闭 AI bridge、GPT-SoVITS 和手动启动的 Ollama。关闭电脑端服务不会修改 ESP32 固件。

## 独立人格、音色与项目控制台（2026-09-29，本轮）

启动器现在分别选择人格和GPT-SoVITS音色。下拉框表示“已选择”，顶部状态表示服务端“实际激活”；选择后不会自动切换。点击“验证选择/显示路径”自动检查文件和SHA256，并显示人格正文路径、两份权重、参考WAV及配置。

- **完整启动**：检查端口，依次等待Ollama、GPT-SoVITS、AI bridge及预热。旧bridge API需要在原窗口退出后重启，不能根据端口杀进程。
- **切换人格**：只加载提示词、清空短期历史，不调用权重接口。
- **切换音色**：保留人格和历史，成对热加载权重。失败恢复原权重；恢复失败隔离GPT-SoVITS，实际SAPI回退状态明确显示。
- **应用组合**：应用两个选择；权重失败不激活新组合。缓存绑定persona_id、voice_id、提示词和音色版本，保留历史缓存，不自动批量生成。

人格档案位于server/personas/<id>.local.json，正文位于server/prompts/<id>.txt。音色档案位于server/voices/<id>.local.json。roles支持仅含persona_id、voice_id的可选预设，同时保留旧完整角色格式；已有New_ManBoo可兼容迁移。首次启动缺少独立档案时从旧默认角色创建缺失档案，不覆盖原文件。新导入正文保存为独立UTF-8 TXT，模型与WAV保留在原位置。

“导入音色”选择.ckpt、.pth、WAV并填写逐字原文、模型版本、语言和音色版本。程序自动计算SHA256并保存配对记录；哈希检测文件是否变化，不能证明两份权重属于同次训练，导入时仍需选择正确的成对结果。已有ID不覆盖，修改音色请使用新ID/版本。example配置只作字段说明；本地配置、导入正文、模型、录音和日志不提交Git。

控制台包含汇总、Ollama、GPT-SoVITS、AI bridge、ESP32串口页。新增日志不自动滚到底部；清空显示/界面裁剪不删除磁盘日志。server/logs/launcher按本机日期和来源分文件，单段约2MiB后创建新编号段，不自动删除历史段。每行含本机时间、来源、请求ID，无关联请求时为“-”。外部服务只能健康检查，无法取得其历史控制台输出。

串口需安装pyserial（在可见终端运行python -m pip install pyserial）。先退出PlatformIO监视器，再刷新COM并连接115200；占用时直接报错，不抢占。连接不自动发送命令；文本输入及常用按钮仅在手动点击后发送，不自动烧录或发送舵机动作。关闭App断开串口。

交互测试页使用实际激活组合：人格对话调用/debug/dialogue；音色试听调用/debug/tts；完整文字链路通过/debug/text-chain在同一组合事务中先生成回复再合成。结果显示回复、情绪、动作、后端、耗时和生成文件；点击“电脑播放结果”才本地播放，不发送给ESP32。SAPI回退不代表自定义音色联调通过。

音色训练页列出授权素材、3～10秒切片、逐句标注、格式化、SoVITS/GPT训练、成对权重和参考原文要求。“启动训练WebUI”调用已有脚本并打开**可见外部PowerShell终端**，不自动训练；9874已占用则不重复启动。通过系统外部浏览器打开9874，训练终端中Ctrl+C停止。该独立终端不随App退出终止，以免中断用户后来手动开始的训练。页面提供数据目录、教学和结果导入入口。

验证在VS Code可见终端执行tools/verify_roles_launcher.ps1（服务端离线测试、真实Tk源码窗口开关、platformio run，不烧录），再执行tools/build_launcher.ps1（PyInstaller及EXE真实窗口开关）。本轮验证结果见task_progress；源码/EXE烟测不等于真实模型、串口或硬件实测。

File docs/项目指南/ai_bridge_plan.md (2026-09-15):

# AI 电脑服务器桥接方案

本文档记录“毛绒治愈机器人 PRP”项目的第一版联网语音桥接方案。后续方案说明和测试步骤默认使用中文维护。

## 一、目标

ESP32-S3 不直接承担大模型推理和高质量语音合成，而是作为本地感知与执行前端：

- 本地唤醒词检测；
- 麦克风录音；
- 扬声器播放；
- 舵机、触摸、震动、加热等身体反馈控制；
- 网络请求电脑服务器；
- 接收服务器返回的回复文本、动作意图和后续音频资源。

电脑服务器负责更重的 AI 能力：

- ASR：把用户语音转成文本；
- LLM：理解用户意图并生成治愈型回复；
- TTS：生成个性化、柔和音色的语音；
- 动作意图规划：告诉 ESP32 应该触发哪类身体反馈。

## 二、第一版最小链路

当前已实现的是“网络通路验证版”，还不是完整 AI 对话版。

流程如下：

1. ESP32-S3 启动后尝试连接 Wi-Fi。
2. 如果 Wi-Fi 配置为空或连接失败，则跳过 AI bridge，保留原来的本地语音命令测试模式。
3. 用户说出本地唤醒词后，ESP32 播放本地欢迎音频，作为“可以开始说话”的提示。
4. 欢迎音频播放结束后，ESP32 录制约 5 秒 PCM 音频，格式为 16 kHz、16 bit、mono。
5. ESP32 通过 HTTP POST 把原始 PCM 音频上传到电脑服务器。
6. 电脑服务器保存这段 PCM 文件，并返回一段测试 JSON。
7. ESP32 解析 JSON，打印回复文本，并根据 `motion` 字段触发已有动作函数。
8. 处理完成后返回等待唤醒状态。

## 三、当前 ESP32 配置文件

联网配置在：

```text
E:\Projects2026\Prp_voice_servo_unified\main\network_config.h
```

需要关注的字段：

| 字段 | 作用 |
| --- | --- |
| `WIFI_SSID` | Wi-Fi 名称。 |
| `WIFI_PASSWORD` | Wi-Fi 密码。 |
| `AI_SERVER_URL` | 电脑服务器接口地址。 |
| `AI_BRIDGE_ENABLED` | 是否启用 AI bridge 逻辑。 |
| `AI_RECORD_DURATION_MS` | 欢迎音频播放结束后的录音时长，当前默认 5000 ms。 |

示例：

```cpp
#define WIFI_SSID "你的WiFi名称"
#define WIFI_PASSWORD "你的WiFi密码"
#define AI_SERVER_URL "http://192.168.1.23:8000/voice/interact"
```

注意：电脑和 ESP32-S3 必须连接到同一个局域网。

## 四、电脑测试服务器

测试服务器文件：

```text
E:\Projects2026\Prp_voice_servo_unified\server\ai_bridge_server.py
```

依赖文件：

```text
E:\Projects2026\Prp_voice_servo_unified\server\requirements.txt
```

服务器启动后，会提供两个接口：

| 接口 | 作用 |
| --- | --- |
| `GET /health` | 检查服务器是否正常运行。 |
| `POST /voice/interact` | 接收 ESP32 上传的 PCM 音频，并返回测试 JSON。 |

当前服务器会把收到的录音保存到：

```text
E:\Projects2026\Prp_voice_servo_unified\server\recordings
```

服务器会同时保存：

- `.pcm`：ESP32 上传的原始音频；
- `.wav`：自动转换后的可播放录音。

可以访问：

```text
http://127.0.0.1:8000/recordings
```

查看所有录音，再通过返回的 `url` 下载或播放对应 `.wav` 文件。

## 五、电脑服务器代码结构

| 文件 | 作用 |
| --- | --- |
| `server\ai_bridge_server.py` | FastAPI 主服务，负责接收音频、保存文件、返回结果。 |
| `server\services\asr_service.py` | ASR 占位层，后续接 Whisper、faster-whisper 或 SenseVoice。 |
| `server\services\dialogue_service.py` | 对话生成占位层，后续接本地/云端大模型。 |
| `server\services\tts_service.py` | TTS 占位层，后续接 CosyVoice、GPT-SoVITS、Fish Speech 或 Kokoro。 |
| `server\recordings` | 保存 ESP32 上传的录音。 |

## 六、服务器返回 JSON 约定

当前测试服务器返回：

```json
{
  "reply_text": "我收到你的声音了，下一步会在这里接入语音识别和治愈回复。",
  "motion": "comfort",
  "audio_url": "",
  "debug_recording": "recording_xxx_16000hz.pcm"
}
```

ESP32 当前会处理：

| 字段 | 当前用途 |
| --- | --- |
| `reply_text` | 在串口日志中打印，暂时不会被 ESP32 朗读。 |
| `motion` | 转换为本地动作函数。 |
| `audio_url` | 已预留，后续用于服务器返回动态语音地址。 |
| `debug_recording` | 服务器侧调试字段，ESP32 当前不依赖。 |

当前支持的动作意图：

| `motion` 值 | ESP32 动作 |
| --- | --- |
| `happy` | `robot_motions.actionHappy()` |
| `shy` | `robot_motions.actionShy()` |
| `comfort` | `robot_motions.actionCurious()` |
| `curious` | `robot_motions.actionCurious()` |
| `none` | 不触发动作 |

## 七、下一步开发方向

第一版只打通“录音上传 + JSON 返回 + 动作意图”的通路。后续建议按顺序继续：

1. 在电脑服务器中接入 ASR，把 PCM 转文字。
2. 接入大模型，根据用户文本生成治愈型回复。
3. 接入 TTS，生成柔和个性化音色。
4. 让服务器返回 16 kHz、16 bit、mono 的 PCM/WAV。
5. ESP32 下载或流式接收音频并通过 MAX98357A 播放。
6. 将服务器返回的动作、震动、加热意图统一接入机器人执行层。

## 八、当前 AI 服务层状态

当前已经搭建完成：

- ASR 服务层：默认占位，可切换为 `faster_whisper`；
- 对话生成层：默认规则兜底，可切换为本地 Ollama；
- TTS 服务层：当前占位，音效和个性化语音后续再接；
- 调试接口：`/config`、`/recordings`、`/debug/pipeline/{file_name}`。

当前服务器返回 JSON 会包含：

| 字段 | 作用 |
| --- | --- |
| `recognized_text` | ASR 识别文本。占位模式下为空。 |
| `asr_status` | ASR 状态，例如 `disabled`、`ok`、`missing_dependency`。 |
| `asr_backend` | 当前 ASR 后端。 |
| `asr_detail` | ASR 失败时的具体原因，便于排查模型下载或加载问题。 |
| `reply_text` | 生成的回复文本。 |
| `llm_status` | 回复生成状态，例如 `rule`、`ok`、`fallback_no_text`。 |
| `llm_backend` | 当前回复生成后端。 |
| `motion` | 返回给 ESP32 的动作意图。 |

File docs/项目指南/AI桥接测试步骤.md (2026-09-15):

# AI 电脑服务器桥接测试步骤

本文档用于手把手测试第一版 AI bridge：ESP32-S3 唤醒后录音，并把音频通过 Wi-Fi 发到电脑服务器。

## 一、测试前确认

你需要准备：

- ESP32-S3；
- INMP441 麦克风模块；
- MAX98357A 功放和扬声器；
- 电脑；
- 电脑和 ESP32-S3 能连接到同一个 Wi-Fi；
- 当前工程：`E:\Projects2026\Prp_voice_servo_unified`。

当前第一版只验证：

- ESP32 能连 Wi-Fi；
- ESP32 能访问电脑服务器；
- 唤醒后能录音；
- 电脑能收到并保存 PCM 音频；
- 电脑能返回 JSON；
- ESP32 能解析回复并触发动作意图。

当前第一版还没有完成：

- ASR 语音转文字；
- 大模型回复；
- 个性化 TTS；
- 服务器动态语音回传播放。

## 二、启动电脑测试服务器

打开一个新的 PowerShell 终端，执行：

```powershell
cd E:\Projects2026\Prp_voice_servo_unified\server
python -m pip install -r requirements.txt
python -m uvicorn ai_bridge_server:app --host 0.0.0.0 --port 8000
```

如果启动成功，终端会显示类似：

```text
Uvicorn running on http://0.0.0.0:8000
```

这个终端不要关，它就是电脑服务器。

## 三、确认电脑服务器可访问

再打开一个 PowerShell 终端，执行：

```powershell
curl http://127.0.0.1:8000/health
```

如果正常，会返回类似：

```json
{"status":"ok"}
```

如果这一步失败，先不要烧录 ESP32，说明电脑服务器还没跑起来。

## 四、查看电脑局域网 IP

在 PowerShell 执行：

```powershell
ipconfig
```

找到当前正在使用的无线网卡，记录其中的 `IPv4 地址`。它通常长这样：

```text
192.168.1.23
```

注意不要用：

- `127.0.0.1`；
- `localhost`；
- 虚拟网卡 IP；
- 蓝牙网卡 IP。

ESP32 要访问的是电脑在局域网里的 IPv4 地址。

## 五、修改 ESP32 网络配置

打开：

```text
E:\Projects2026\Prp_voice_servo_unified\main\network_config.h
```

把里面改成你的 Wi-Fi 和电脑 IP，例如：

```cpp
#define WIFI_SSID "你的WiFi名称"
#define WIFI_PASSWORD "你的WiFi密码"
#define AI_SERVER_URL "http://192.168.1.23:8000/voice/interact"
```

其中 `192.168.1.23` 要换成你自己电脑 `ipconfig` 看到的 IPv4 地址。

## 六、先编译，不急着上传

在 PowerShell 执行：

```powershell
cd E:\Projects2026\Prp_voice_servo_unified
platformio run
```

看到下面这行才表示编译成功：

```text
[SUCCESS]
```

`platformio run` 只编译，不会改 ESP32 板子里的固件。

## 七、确认后再上传固件

只有在你确认可以覆盖当前板子固件时，才执行：

```powershell
cd E:\Projects2026\Prp_voice_servo_unified
platformio run -t upload
```

如果上传失败，常见处理：

- 确认 ESP32 接的是能下载程序的 USB 口；
- 确认没有串口监视器占用 COM 口；
- 必要时按住 BOOT，再点一下 RESET，然后重新上传。

## 八、打开串口日志

上传完成后，打开串口监视器：

```powershell
pio device monitor -p COM7 -b 115200
```

如果你的端口不是 COM7，可以先查看设备：

```powershell
pio device list
```

在日志里重点看：

- 是否连接 Wi-Fi 成功；
- 是否打印 ESP32 获得的 IP；
- 是否进入等待唤醒状态；
- 唤醒后是否开始录音；
- 是否打印上传到 AI server；
- 是否打印服务器返回的 `reply_text` 和 `motion`。

## 九、实际语音测试

保持电脑服务器终端运行。

对着麦克风说唤醒词：

```text
你好小智
```

如果唤醒成功，ESP32 会：

1. 播放本地欢迎音频；
2. 欢迎音频播放结束后，录制约 5 秒声音；
3. 上传到电脑服务器；
4. 在串口里打印服务器返回内容；
5. 如果返回 `motion=comfort`，尝试触发 `actionCurious()`。

电脑服务器终端应该看到类似：

```text
[ai_bridge] received 96000 bytes, format=pcm_s16le_mono, sample_rate=16000, saved=recording_xxx_16000hz.pcm
```

如果看到这行，说明“ESP32 到电脑服务器”的核心链路已经通了。

## 十、查看录音文件

服务器保存的录音在：

```text
E:\Projects2026\Prp_voice_servo_unified\server\recordings
```

当前服务器会同时保存两种文件：

| 文件类型 | 用途 |
| --- | --- |
| `.pcm` | ESP32 上传的原始音频数据。 |
| `.wav` | 自动转换后的可播放音频，用于检查麦克风录音质量。 |

查看服务器收到的录音列表：

```powershell
curl http://127.0.0.1:8000/recordings
```

也可以在浏览器打开：

```text
http://127.0.0.1:8000/recordings
```

列表里会出现类似：

```json
{
  "name": "recording_20260830_171812_081721_16000hz.wav",
  "size": 95276,
  "url": "/recordings/recording_20260830_171812_081721_16000hz.wav"
}
```

要播放某条录音，把 `url` 拼到服务器地址后面，例如：

```text
http://127.0.0.1:8000/recordings/recording_20260830_171812_081721_16000hz.wav
```

如果你能听见刚才对 ESP32 说的话，说明麦克风录音、上传和服务器保存都正常。

## 十一、当前服务器代码结构

当前电脑服务器已经拆出 AI 服务框架：

| 文件 | 作用 |
| --- | --- |
| `server\ai_bridge_server.py` | FastAPI 主服务，负责接收音频、保存文件、返回结果。 |
| `server\services\asr_service.py` | ASR 占位层，后续接 Whisper、faster-whisper 或 SenseVoice。 |
| `server\services\dialogue_service.py` | 对话生成占位层，后续接本地/云端大模型。 |
| `server\services\tts_service.py` | TTS 占位层，后续接 CosyVoice、GPT-SoVITS、Fish Speech 或 Kokoro。 |
| `server\recordings` | 保存 ESP32 上传的录音。 |

现在 `/voice/interact` 已经按下面的顺序调用：

```text
保存 PCM
-> 转成 WAV
-> ASR 占位
-> 治愈回复生成占位
-> TTS 占位
-> 返回 JSON 给 ESP32
```

## 十二、常见问题

### 1. ESP32 日志提示 `WIFI_SSID is empty`

说明你还没有修改：

```text
E:\Projects2026\Prp_voice_servo_unified\main\network_config.h
```

此时 AI bridge 会跳过，系统会继续使用本地命令词模式。

### 2. ESP32 连不上 Wi-Fi

检查：

- Wi-Fi 名称和密码是否正确；
- Wi-Fi 是否是 2.4 GHz；
- ESP32 和电脑是否在同一个网络；
- 手机热点是否开启了设备隔离。

如果串口输入 `retry wifi` 后显示：

```text
Wi-Fi retry result: ESP_ERR_NOT_FOUND
```

优先检查工程的 `partitions.csv` 是否包含 `nvs` 分区。ESP-IDF Wi-Fi 需要 NVS 分区才能启动。

### 3. 电脑服务器能本机访问，但 ESP32 访问失败

检查：

- `AI_SERVER_URL` 里不能写 `127.0.0.1`；
- 必须写电脑的局域网 IPv4；
- Windows 防火墙可能拦截了 8000 端口；
- 电脑和 ESP32 是否连在同一个路由器或热点下。

### 4. 电脑收不到录音

检查：

- 服务器终端是否还开着；
- 端口是否是 8000；
- `AI_SERVER_URL` 是否写成 `/voice/interact`；
- ESP32 串口日志是否显示 HTTP 请求失败。

### 5. 有动作日志但没接舵机

这是正常的。当前动作意图会调用已有动作函数，如果 PCA9685 没连接，动作模块可能跳过执行。单测语音桥接时可以先不接舵机。

## 十三、录音时机与音量调试

当前 AI bridge 模式下，唤醒词识别成功后会先播放本地欢迎音频。欢迎音频播放结束后，串口会打印 `AI bridge recording started`，此时开始录音；录音窗口默认持续 5 秒，结束后上传到电脑服务器处理。

如果 AI bridge 不可用，系统仍然回退到本地命令词模式。若 AI bridge 在录音或上传阶段失败，系统会进入本地命令词模式，方便继续验证离线命令词。

上传录音有独立数字增益，配置位置：

```text
E:\Projects2026\Prp_voice_servo_unified\main\network_config.h
```

当前默认：

```cpp
#define AI_RECORD_DURATION_MS 5000
#define AI_RECORD_GAIN 3
```

如果录音仍然偏小，可以尝试改成 `4` 或 `5`；如果声音破音、爆音或噪声明显，则改回 `2` 或 `1`。

## 十四、整体 AI 链路调试

当前电脑服务器已经跑通下面这条结构：

```text
ESP32 上传 PCM
-> 服务器保存 PCM
-> 服务器转换 WAV
-> ASR 服务层
-> 治愈回复生成层
-> TTS 生成回复 WAV
-> ESP32 下载并播放回复音频
-> 返回 JSON 给 ESP32
```

当前为了保证链路稳定，ASR 默认还是占位模式。也就是说，服务器会明确返回：

```json
{
  "asr_status": "disabled",
  "asr_backend": "placeholder"
}
```

这不是错误，而是表示“语音转文字模型尚未启用”。

查看当前服务器配置：

```powershell
curl http://127.0.0.1:8000/config
```

用已有 WAV 录音跑一遍服务器 AI 管线：

```powershell
curl http://127.0.0.1:8000/debug/pipeline/你的录音文件名.wav
```

录音文件名可以从这里查看：

```powershell
curl http://127.0.0.1:8000/recordings
```

如果要启用本地 ASR，下一步计划使用 `faster-whisper`。操作思路是：

1. 安装 ASR 依赖：

```powershell
cd E:\Projects2026\Prp_voice_servo_unified\server
python -m pip install -r requirements-asr.txt
```

2. 修改服务器配置：

```text
E:\Projects2026\Prp_voice_servo_unified\server\server_config.py
```

把：

```python
ASR_BACKEND = "placeholder"
```

改成：

```python
ASR_BACKEND = "faster_whisper"
```

3. 重启服务器。

第一次启用 `faster-whisper` 时，可能需要下载模型。当前默认模型是 `tiny`，优先用于跑通链路；后续如果识别准确率不够，再升级到 `base` 或 `small`。

## 十五、当前 ASR 状态

当前服务器已经安装 `faster-whisper`，并把 ASR 后端切换为：

```python
ASR_BACKEND = "faster_whisper"
```

配置位置：

```text
E:\Projects2026\Prp_voice_servo_unified\server\server_config.py
```

为了适配国内网络，服务器配置中已经加入：

```python
HF_ENDPOINT = "https://hf-mirror.com"
HF_HUB_DISABLE_XET = "1"
```

当前上传录音会做服务端音量归一化：

```python
AUDIO_NORMALIZE_TARGET_PEAK = 0.75
```

一次旧录音测试中，原始录音峰值只有约 2.5%，归一化后提升到约 75%。归一化后的旧录音可以被 ASR 识别，但只识别出“啊”，说明旧录音里的有效语音内容不足。下一步应使用已经提前录音、增加上传增益的新 ESP32 固件重新录制完整短句，再观察 `recognized_text`。

## 十六、语音回复链路测试

当前服务端已经接入 Windows SAPI 作为轻量 TTS 后端，用于优先测试“文字转音频 + ESP32 下载播放”的整体延迟。它不是最终音色方案，主要用于验证链路速度和稳定性。

完整流程：

```text
ESP32 唤醒
-> 播放本地欢迎音
-> 录音 5 秒
-> 上传 PCM 到电脑服务器
-> 服务端 ASR
-> 生成回复文本
-> 服务端生成 reply_xxx_16000hz.wav
-> 返回 audio_url 和 timings_ms
-> ESP32 下载 WAV
-> 跳过 WAV 头，播放 PCM 数据
```

服务端日志重点看：

```text
[ai_bridge] recognized='...'
tts=ok/windows_sapi
audio_url=/recordings/reply_xxx_16000hz.wav
timings_ms={...}
```

ESP32 串口日志重点看：

```text
AI bridge recording started
AI bridge recording finished
AI reply: recognized='...', ..., audio_url='/recordings/reply_xxx_16000hz.wav'
Downloading reply audio
Reply audio downloaded
Reply audio playback starting
Reply audio playback finished
```

本地测试某条录音是否能生成回复音频：

```powershell
cd E:\Projects2026\Prp_voice_servo_unified
$env:PYTHONIOENCODING='utf-8'; python server\tools\test_asr_file.py server\recordings\你的录音文件名.wav
```

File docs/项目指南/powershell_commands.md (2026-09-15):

# PowerShell 指令速查表

本文档记录 PRP 语音舵机统一工程常用的 PowerShell 指令。默认工程路径为：

```powershell
cd E:\Projects2026\Prp_voice_servo_unified
```

## 一、进入工程目录

每次打开新的 PowerShell 后，先进入工程目录：

```powershell
cd E:\Projects2026\Prp_voice_servo_unified
```

如果要进入电脑服务器目录：

```powershell
cd E:\Projects2026\Prp_voice_servo_unified\server
```

## 二、只编译，不烧录

用于检查代码是否能通过编译，不会改 ESP32 板子里的固件：

```powershell
platformio run
```

看到类似下面内容表示编译成功：

```text
[SUCCESS]
```

## 三、上传固件到 ESP32

上传前先关闭串口监视器，否则可能出现 `COM7 is busy` 或 `拒绝访问`。

```powershell
platformio run -t upload
```

如果自动识别端口失败，可以指定端口：

```powershell
platformio run -t upload --upload-port COM7
```

如果烧录时一直连接不上，可以按住开发板 `BOOT` 键，再执行上传命令；看到开始写入后松开 `BOOT`。

## 四、查看串口设备列表

用于确认 ESP32 当前是哪个 COM 口：

```powershell
pio device list
```

当前项目常见端口是：

```text
COM7
```

## 五、打开串口监视器

上传完成后再打开串口监视器：

```powershell
pio device monitor -p COM7 -b 115200
```

如果你的板子不是 `COM7`，把 `COM7` 换成 `pio device list` 看到的实际端口。

退出串口监视器：

```text
Ctrl + C
```

## 六、串口里常用输入指令

这些不是 PowerShell 命令，而是在串口监视器打开后直接输入并回车。

查看 AI bridge 状态：

```text
status ai bridge
```

重新连接 Wi-Fi：

```text
retry wifi
```

打开机器控制入口：

```text
start machine control
```

关闭机器控制入口：

```text
end machine control
```

打开机器动作日志：

```text
start log machine
```

关闭机器动作日志：

```text
end log machine
```

## 七、启动电脑 AI 服务器

打开一个新的 PowerShell，执行：

```powershell
cd E:\Projects2026\Prp_voice_servo_unified\server
python -m uvicorn ai_bridge_server:app --host 0.0.0.0 --port 8000
```

这个窗口不要关。ESP32 上传录音时，需要这个服务器一直运行。

## 八、检查电脑服务器是否正常

另开一个 PowerShell，执行：

```powershell
curl http://127.0.0.1:8000/health
```

正常会返回：

```json
{"status":"ok"}
```

查看服务器配置：

```powershell
curl http://127.0.0.1:8000/config
```

重点看：

```json
"asr_backend": "faster_whisper"
```

## 九、查看电脑局域网 IP

ESP32 不能访问电脑的 `127.0.0.1`，需要使用电脑在当前 Wi-Fi 或热点下的 IPv4 地址。

```powershell
ipconfig
```

找到正在使用的无线网卡，看这一行：

```text
IPv4 地址 . . . . . . . . . . . . : 192.168.xx.xx
```

然后确认 `main\network_config.h` 里的服务器地址类似：

```cpp
#define AI_SERVER_URL "http://192.168.xx.xx:8000/voice/interact"
```

## 十、查看服务器收到的录音

查看录音列表：

```powershell
curl http://127.0.0.1:8000/recordings
```

录音文件保存在：

```text
E:\Projects2026\Prp_voice_servo_unified\server\recordings
```

每次 ESP32 上传成功后，一般会生成：

```text
recording_xxx_16000hz.pcm
recording_xxx_16000hz.wav
```

其中 `.wav` 可以直接播放，用来检查麦克风录音质量。

## 十一、用本地录音测试 ASR 管线

把文件名换成你要测试的录音：

```powershell
cd E:\Projects2026\Prp_voice_servo_unified
$env:PYTHONIOENCODING='utf-8'; python server\tools\test_asr_file.py server\recordings\你的录音文件名.wav
```

例如：

```powershell
$env:PYTHONIOENCODING='utf-8'; python server\tools\test_asr_file.py server\recordings\recording_20260901_004107_663887_16000hz.wav
```

重点看：

```text
recognized_text
asr_status
reply_text
motion
```

## 十二、常见问题

### 1. 烧录时报 COM 口被占用

报错类似：

```text
Could not open COM7, the port is busy or doesn't exist.
PermissionError(13, '拒绝访问。')
```

处理方式：

1. 关闭串口监视器。
2. 关闭 Arduino IDE、串口助手、其他占用 COM 口的软件。
3. 拔掉 ESP32 USB，等几秒再插回。
4. 重新执行上传命令。

### 2. ESP32 连不上电脑服务器

检查：

- 电脑服务器窗口是否还开着。
- ESP32 和电脑是否在同一个 Wi-Fi 或热点。
- `AI_SERVER_URL` 是否写的是电脑局域网 IPv4，而不是 `127.0.0.1`。
- Windows 防火墙是否拦截 8000 端口。

### 3. 修改代码后不知道先做什么

推荐顺序：

```powershell
platformio run
platformio run -t upload
pio device monitor -p COM7 -b 115200
```

也就是：

```text
先编译 -> 再上传 -> 再打开串口看日志
```

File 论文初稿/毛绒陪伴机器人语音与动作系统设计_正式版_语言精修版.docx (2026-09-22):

项目编号：

本科生研究计划（PRP）研究论文

(第 期)

论文题目：_______________________________________

项目负责人：_________ 学院（系）： _______________

指导教师：_________ 学院（系）： _______________

参与学生：_______________________________________

项目执行时间：_____年_____月 至 _____年_____月

摘要

面向日常陪伴场景中用户对自然语音交互、情绪回应和具身动作反馈的需求，本文设计并实现了一套毛绒陪伴机器人语音与动作系统。系统以 ESP32-S3 为本地感知与执行终端，连接 INMP441 数字麦克风、MAX98357A 数字功放、扬声器、PCA9685 舵机驱动板及四个脚部舵机和一个尾巴舵机；电脑端 AI bridge 负责语音识别、对话生成和语音合成。用户说出唤醒词后，设备进行端点检测录音，并通过 Wi-Fi 将 16 kHz PCM 语音上传至服务端；服务端依次完成 faster-whisper 语音识别、基于“糯糯”角色提示词的 Ollama 对话生成及 TTS 合成，返回回复文本、动作意图、耗时和音频地址。ESP32 下载并播放 WAV 音频，同时将动作意图投入 FreeRTOS 动作队列，由 PCA9685 输出五路 PWM 信号。开发过程中，系统完成了录音方式、识别参数、角色配置、语音合成、触摸输入和舵机供电方案的改进。当前语音链路和舵机通道0已经完成实际验证，下一阶段将围绕五舵机协同运行、连续对话和量化评价展开。

关键词：毛绒机器人，语音交互，ESP32-S3，动作控制，陪伴机器人

ABSTRACT

This study designs and implements a voice and motion system for a plush companion robot. An ESP32-S3 serves as the local sensing and execution terminal and connects to an INMP441 digital microphone, a MAX98357A audio amplifier, a loudspeaker, a PCA9685 servo driver, four leg servos and one tail servo. A computer-side AI bridge performs speech recognition, dialogue generation and speech synthesis. After wake-word detection, the device records speech through endpoint detection and uploads 16 kHz PCM audio through Wi-Fi. The server uses faster-whisper for speech recognition, Ollama with the Nuonuo persona prompt for dialogue generation, and SAPI or GPT-SoVITS for speech synthesis. It returns the reply text, motion intent, timing information and an audio URL. The ESP32 downloads and plays the WAV audio while dispatching motion intents to a FreeRTOS queue. The voice pipeline and servo channel 0 have completed physical verification. The next stage focuses on coordinated five-servo operation, continuous dialogue and quantitative evaluation.

KEY WORDS：plush robot, voice interaction, ESP32-S3, motion control, companion robot

# 1 绪论

## 1.1 研究背景

毛绒玩具具有柔软、低压力和容易亲近的外观特点，适合承载轻量化的陪伴交互。与只能播放固定音频的玩具相比，带有语音理解、回复语音和动作反馈能力的毛绒机器人，能够在用户表达疲惫、开心、焦虑或希望被陪伴时，给出相对自然的回应，并通过身体动作增强交互感受。

本项目以“糯糯”毛绒小龙为机器人形象，目标不是构建医疗诊断或心理治疗设备，而是实现一个可进行日常短对话、提供温和陪伴和做出简单肢体反馈的原型系统。系统设计需要同时处理嵌入式端本地唤醒与录音、无线音频传输、电脑端 AI 服务调用、语音播放、五路舵机控制以及移动供电条件下的稳定性。

## 1.2 研究目标与内容

本研究拟完成一个由嵌入式终端和电脑端 AI bridge 共同组成的语音交互系统。ESP32-S3 负责本地唤醒词检测、麦克风采集、网络通信、回复音频播放和动作执行；电脑端负责语音识别、大语言模型回复和语音合成。这样的分工避免将较大的 ASR、LLM 和 TTS 模型部署到资源有限的单片机中，同时保留机器人本地的声音输入、声音输出和动作能力。

本文围绕硬件结构、语音数据流、动作调度、个性化配置和测试方法展开。研究重点包括：设计五路舵机的供电和控制方式；实现唤醒、端点检测录音、PCM 上传、ASR、LLM、TTS、WAV 下载播放和动作执行链路；将角色提示词与业务代码解耦；建立对识别准确率、响应耗时和动作稳定性的测试方案。

## 1.3 研究范围与证据边界

本文重点讨论原型系统的软硬件设计、实现过程和测试方法。当前代码已经配置前左、前右、后左、后右和尾巴五个舵机通道，并实现动作队列与同步插值逻辑。实际硬件验证覆盖 PCA9685 通道0的一只 SG90 舵机，因此本文将“五路控制代码”和“通道0硬件验证”分别表述，确保实现状态与实验依据一致。

服务端采用 faster-whisper small、Ollama qwen2.5:3b 和 Windows SAPI TTS，并完成 GPT-SoVITS 独立接口联调。连续对话固件已经实现“30秒无语音退出、最多8轮”的控制逻辑并通过编译。下一阶段将完成新版固件烧录、五舵机联调和标准语料评价，使软件实现、硬件表现和量化结果形成对应关系。

# 2 系统总体方案

## 2.1 四层架构

系统按职责分为四层。用户交互层负责用户说话、唤醒机器人、收听回复和观察动作；设备感知与执行层负责音频采集、播放和舵机输出；通信与业务调度层负责 Wi-Fi、HTTP、PCM/WAV 处理和 JSON 结果汇总；AI 能力层负责语音识别、对话生成、角色约束、语音合成和动作意图生成。供电系统不属于其中单独一层，而是支撑设备层全部模块的基础设施。

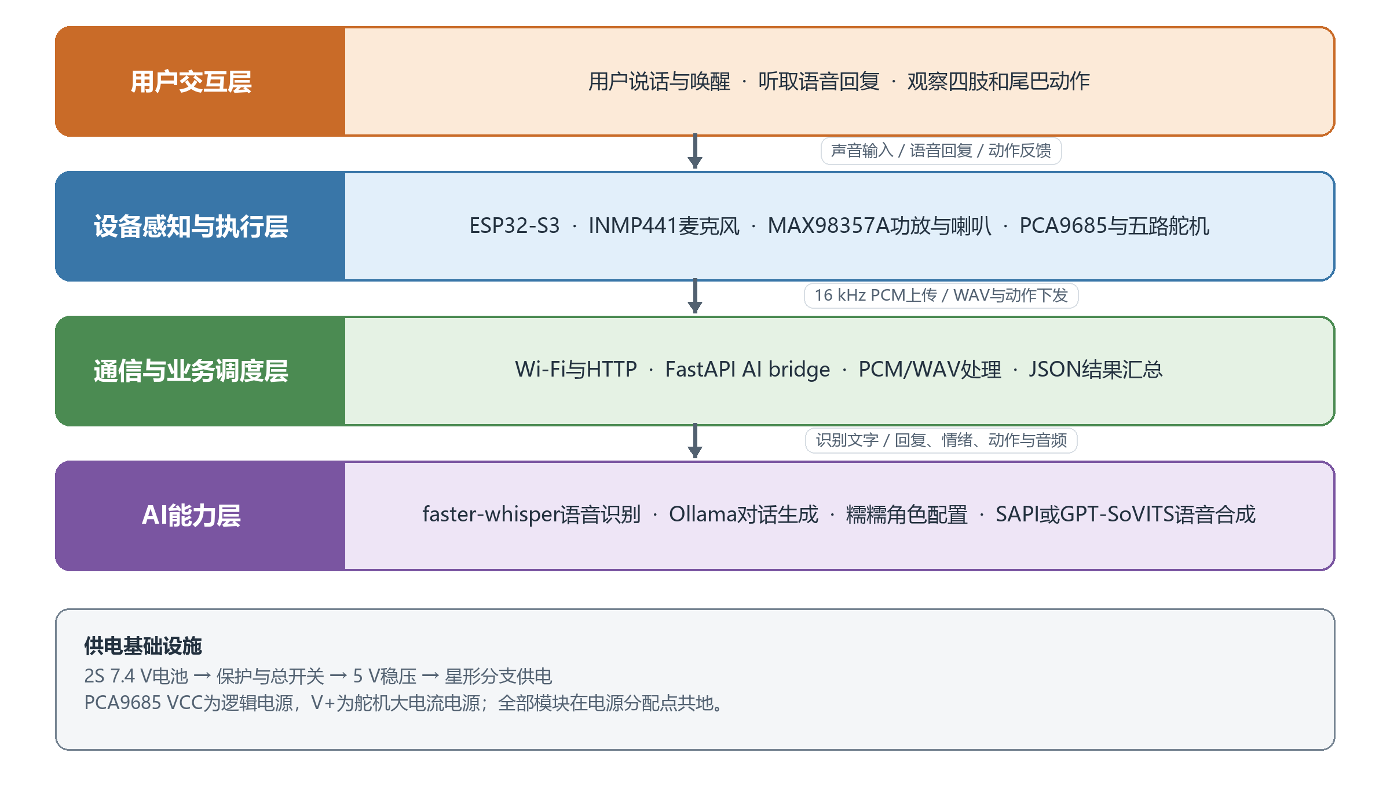
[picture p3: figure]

图2-1 毛绒陪伴机器人四层总体架构

## 2.2 终端与服务端分工

ESP32-S3 侧的任务强调低时延和与物理设备直接相连，包括 WakeNet 本地唤醒、INMP441 音频读取、端点检测、HTTP 上传、WAV 音频播放以及 PCA9685 动作控制。电脑端服务采用 FastAPI 组织 AI bridge，接收原始 PCM 后转换为 WAV，依次调用 ASR、对话服务和 TTS 服务，并以 JSON 返回识别文字、回复、动作、音频地址和耗时。该方式使服务端模型可以独立替换，ESP32 不需要因更换 ASR、LLM 或 TTS 后端而重新设计协议。

## 2.3 已实现状态

子系统 | 当前实现 | 证据状态
本地唤醒 | WakeNet9 与“你好小智”模型 | 已写入代码；历史使用
录音 | 端点检测、噪声基线、pre-roll、静音结束 | 已写入代码；下一步形成量化结果
AI bridge | PCM 上传、ASR、Ollama、TTS、JSON 返回 | 已写入代码；历史端到端日志
连续对话 | 最多8轮、30秒无语音退出 | 已完成代码与编译；下一步完成烧录验证
动作控制 | 五路配置、队列、同步插值 | 已编译；通道0单机实测
五舵机整机 | 并发、负载和温升 | 下一阶段开展并发、负载和温升实验

# 3 硬件系统设计

## 3.1 硬件组成与职责

硬件部分以 ESP32-S3 为核心。INMP441 是数字 MEMS 麦克风，使用 I2S 输出音频数据；MAX98357A 是 I2S 数字功放，将 ESP32 输出的数字音频转换为可驱动喇叭的信号；PCA9685 是16通道 PWM 驱动器，通过 I2C 接收控制命令后输出舵机脉冲。系统使用 PCA9685 的前五个通道分别连接四个脚部舵机和一个尾巴舵机，使各肢体能够独立校准并执行组合动作。

模块 | 作用 | 当前状态
ESP32-S3 | 本地语音、Wi-Fi、播放和动作调度 | 当前统一工程主控
INMP441 | 采集用户语音并输出 I2S 数据 | GPIO 已由代码固定
MAX98357A+喇叭 | 播放欢迎音和服务端回复音频 | 代码支持 WAV 下载与播放
PCA9685 | 输出五路舵机 PWM | 通道0已实际验证
SG90 或后续选型舵机 | 脚部和尾巴姿态动作 | 通道0已验证；下一步扩展其余通道
2S电池、保护、降压 | 移动供电与电压转换 | 采用2S电池和5V星形分支

## 3.2 GPIO 与通信连接

当前固件将 INMP441 的 WS、SCK 和 SD 分别固定为 GPIO4、GPIO5 和 GPIO6；MAX98357A 的 BCLK、LRC 和 DIN 分别使用 GPIO15、GPIO16 和 GPIO7。PCA9685 通过 I2C 与 ESP32-S3 通信，GPIO1 为 SDA，GPIO2 为 SCL，I2C 时钟设为100 kHz。该分配以当前代码为依据，不能沿用早期单舵机直连 GPIO18 的示例。GPIO18 对应的旧 ServoController 文件仍保留在工程中，但不属于当前 PCA9685 五舵机方案。

ESP32-S3 引脚 | 连接模块引脚 | 通信/用途
GPIO4 | INMP441 WS/LRCLK | I2S 输入字选择
GPIO5 | INMP441 SCK/BCLK | I2S 输入位时钟
GPIO6 | INMP441 SD | I2S 输入数据
GPIO7 | MAX98357A DIN | I2S 输出数据
GPIO15 | MAX98357A BCLK | I2S 输出位时钟
GPIO16 | MAX98357A LRC | I2S 输出左右声道时钟
GPIO1 | PCA9685 SDA | I2C 数据
GPIO2 | PCA9685 SCL | I2C 时钟

## 3.3 五路舵机与安全限位

PCA9685 通道0至4依次分配给前左、前右、后左、后右和尾巴。脚部角度范围设置为70°至110°，尾巴设置为60°至120°，主页均为90°。这些参数来自空载台架的安全范围，下一步将结合毛绒骨架、舵机安装方向和机械干涉进行标定。软件会拒绝超出范围的串口命令，降低撞限位和机械卡滞的风险。

PCA9685通道 | 肢体 | 当前范围 | 状态
0 | 前左 | 70°～110° | 已单机实测
1 | 前右 | 70°～110° | 下一步验证
2 | 后左 | 70°～110° | 下一步验证
3 | 后右 | 70°～110° | 下一步验证
4 | 尾巴 | 60°～120° | 下一步验证

## 3.4 供电与共地设计

PCA9685 板上的 VCC 和 V+ 必须区分。VCC 用于驱动芯片的逻辑供电，应接 ESP32 的3.3V；V+ 是舵机供电排，应连接外部稳压5V。舵机的信号电压需要以 ESP32 为参考，因此 ESP32、PCA9685 和外部5V电源必须共地。共地不是让舵机从 ESP32 取电，而是建立统一的信号参考电位。

五个舵机启动、换向或受阻时可能出现较大的瞬时电流。若让它们通过 ESP32 开发板的5V或3.3V引脚供电，可能造成板载稳压器过载、压降或复位，也会把电机噪声带入音频链路。因此，成品设计采用2S电池经过保护、保险丝和总开关后进入5V大电流稳压模块，再以星形分支分别供给 PCA9685 V+、ESP32的5V/VIN和音频模块。舵机支路入口应配置大容量低 ESR 电容，电源线需采用能承载电流的线材；普通杜邦线和面包板不适合承载整机舵机电流。

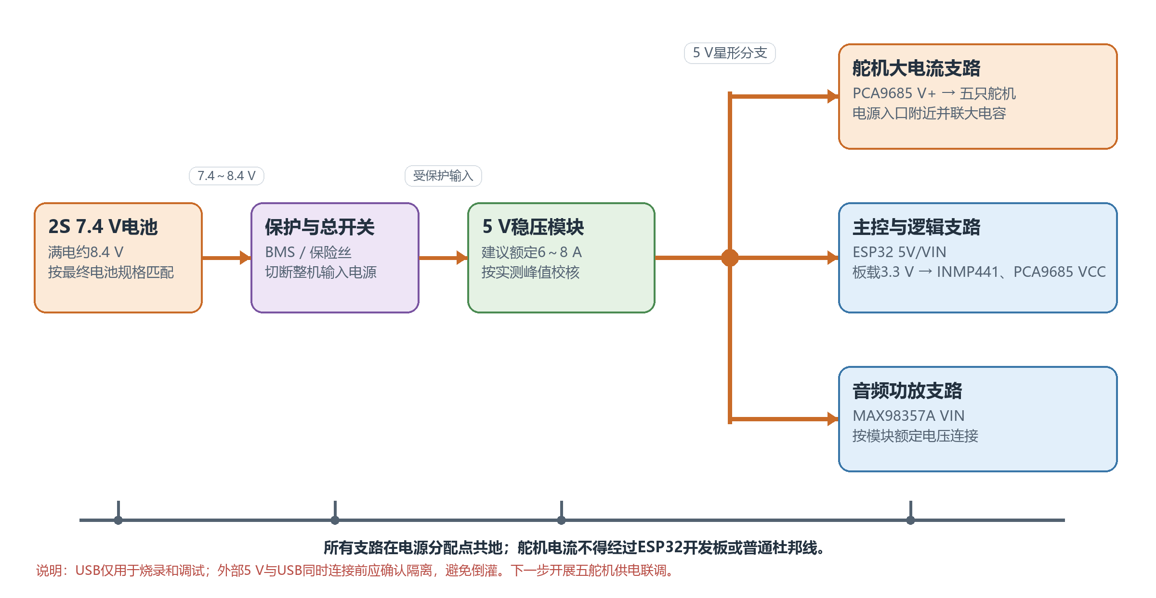
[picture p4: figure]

图3-1 成品供电结构

# 4 软件系统与交互流程

## 4.1 ESP32 语音状态机

设备上电后初始化音频输入输出、唤醒模型、命令词模型、Wi-Fi 和动作模块，并进入等待唤醒状态。检测到“你好小智”后，系统播放本地欢迎音；AI bridge 连接正常时进入端点检测录音，服务不可用时保留本地命令词模式。开发过程中逐步完善了状态日志和前验检查，现在能够显示 Wi-Fi 状态、服务器地址、AI bridge ready 状态及失败原因，从而明确区分网络、服务和录音环节的问题。

端点检测先采集环境噪声估计 noise_floor，然后在等待开口阶段维护短时 pre-roll 环形缓冲。当 RMS 连续超过动态开始阈值达到确认时间后，系统把 pre-roll 写入正式录音并进入录音状态；在达到最短录音时长后，连续静音达到设定时间则结束；达到最长时长时也会强制结束。录音结果是16 kHz、16 bit、单声道 PCM。

## 4.2 AI bridge 调度

ESP32 使用 HTTP POST 上传 PCM，并在请求头中传递采样率和音频格式。FastAPI 服务保存原始 PCM，同时进行音量归一化后写入 WAV。服务端顺序调用 faster-whisper、对话服务和 TTS 服务，最后返回 recognized_text、reply_text、reply_emotion、motion、audio_url、timings_ms 等字段。ASR、LLM 和 TTS 存在数据依赖，因此当前链路以顺序调用为主。

当前 ASR 使用 faster-whisper small、CPU int8、beam_size=5、best_of=5，并关闭跨片段文本条件；识别结果通过 OpenCC 转换为简体。四段旧录音的复查结果表明，small 模型能够改善部分错句。服务端同时提供 benchmark_asr.py 脚本，下一步计划建立带人工参考文本的标准语料，统计 CER、整句正确率和识别耗时。

## 4.3 回复生成、TTS 与动作意图

对话服务默认调用 Ollama 中的 qwen2.5:3b 模型。角色设定存放在独立的 nuonuo_v1.txt 文件中，业务代码通过配置读取，使机器人名称、表达方式和安全边界能够在不修改对话逻辑的情况下切换。模型被要求返回 reply_text、style、emotion 和 motion 字段，服务端再根据用户输入校正情绪与动作，避免负面情绪被误配为 happy。若 Ollama 不可用或返回解析失败，服务端使用规则回复兜底并标记状态。

TTS 服务提供 Windows SAPI 和 GPT-SoVITS 两个后端，输出统一转换为 ESP32 可播放的16 kHz、16 bit、单声道 WAV。当前 AI bridge 使用 Windows SAPI 完成稳定输出，GPT-SoVITS 调试接口已经生成规范 WAV。下一阶段将把自定义音色接入 ESP32 整机链路，比较两种后端的播放效果。ESP32 下载完整 WAV 后解析 data 区块，并通过 I2S 送往 MAX98357A 播放。

## 4.4 动作队列与同步插值

服务端 motion 字段支持 happy、shy、comfort、curious 和 none。ESP32 在机器控制开关开启后，把相应意图投递到长度为8的 FreeRTOS 队列。动作任务根据目标姿态与当前姿态之间的最大角度差确定插值步数，并同步更新五个通道，避免网络、录音或播放任务被长时间动作阻塞。第一版中 comfort 和 curious 共用 curious 动作；下一版将结合机器人外观细化情绪与动作的对应关系。

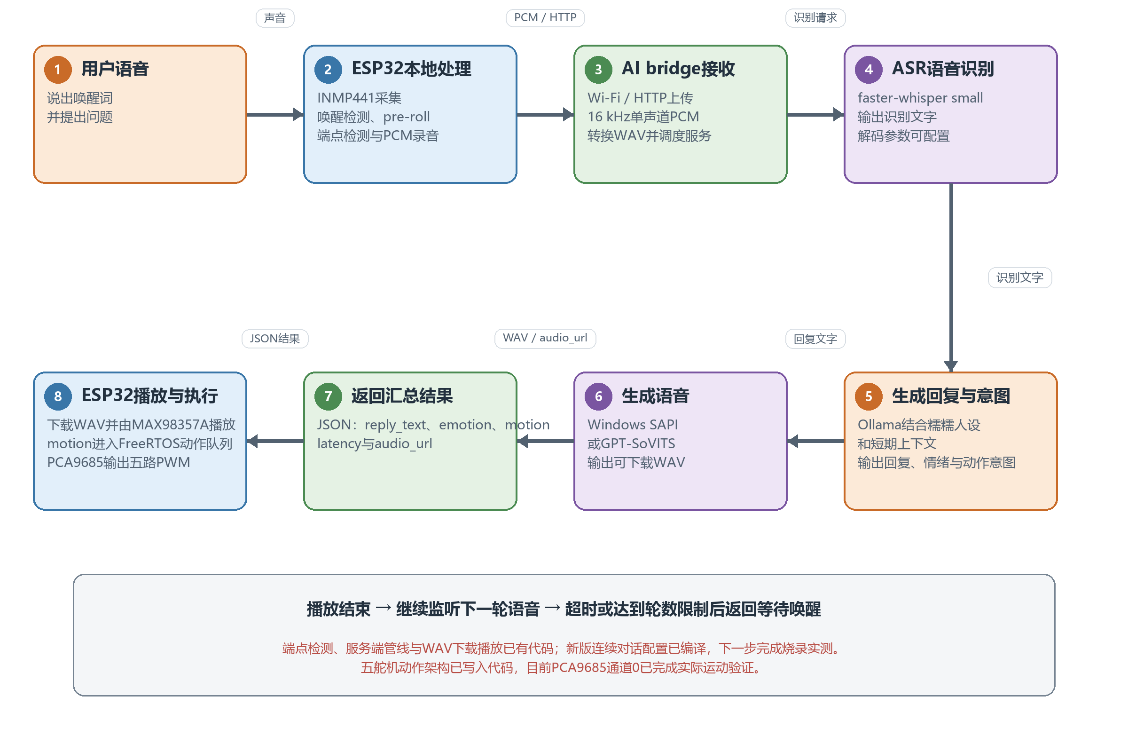
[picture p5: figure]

图4-1 语音交互与动作执行数据流

# 5 个性化设计

## 5.1 角色与回复风格

当前“糯糯”人设描述其为温暖、活泼、略带傲娇的毛绒小龙。提示词同时约束回复应使用简体中文、尽量短、适合语音播放，不进行医学诊断或承诺治疗效果；当出现明显危险、自伤或急症内容时，应鼓励用户寻求现实中的可信任人员或专业帮助。服务端当前提供 cute 和 encourage 两种情境风格，并保留最近四轮对话作为短期上下文。

## 5.2 可配置项目

可配置内容 | 配置位置 | 当前状态
角色名称与提示词 | server/prompts 与环境变量 | 已提供入口
LLM模型、超时与回复风格 | server_config.py / 环境变量 | 已提供入口
ASR模型、beam、best_of、热词 | server_config.py / 环境变量 | 已提供入口；热词默认关闭
TTS后端、参考音频与语言 | server_config.py / 环境变量 | 已提供入口
端点检测阈值与会话时间 | main/network_config.h | 已提供入口
舵机通道、角度范围与主页 | main/robot_config.h | 已提供入口；下一步结合机械结构校准
触摸输入 | main/robot_config.h | 代码预留，默认关闭

配置入口与实际运行效果分开管理。GPT-SoVITS 可以通过配置启用，触摸输入也保留 GPIO 和动作映射；当前默认运行组合为 Windows SAPI 和关闭触摸输入。论文据此区分当前运行配置与下一阶段扩展内容，使个性化能力的描述与系统状态保持一致。

# 6 开发过程与改进

## 6.1 录音与网络链路改进

项目早期采用固定5秒录音，短句会产生多余静音和等待，长句或停顿又容易被截断。之后改用端点检测，根据环境噪声基线、动态阈值、开口确认、pre-roll 和连续静音自动确定录音边界，同时保留最长录音时长作为保护。该方案已经写入当前代码，下一步计划采集更多短句、长句和停顿样本，形成完整率更高的实验结论。

网络链路早期采用静默回退，日志信息较少，难以判断问题位于网络、服务器还是录音模块。开发过程中逐步完善了日志内容和前验保护，在每次唤醒前检查 Wi-Fi 与 AI bridge 状态，并记录服务器地址和失败原因，使故障位置能够被快速识别。

## 6.2 语音识别、回复与合成改进

早期 ASR 使用 tiny 模型，速度较快，但复杂语句和含糊录音的识别效果有限。系统随后升级为 small 模型，并调整 beam_size、best_of、跨片段文本条件和繁简转换。完整提示词和强热词容易在短录音中产生幻听，因此当前默认关闭，只保留配置入口。旧录音复查显示识别结果有所改善，下一步计划用标准语料形成统一的准确率和耗时评价。

回复生成最初以规则话术为主，之后加入 Ollama 本地模型、独立角色提示词、短期上下文、情绪字段和动作字段，使机器人形象能够通过配置切换。语音合成以 Windows SAPI 作为默认后端，同时完成 GPT-SoVITS 参数适配和 WAV 格式统一，为自定义音色接入提供接口。

## 6.3 动作与硬件控制改进

早期动作控制通道较少，并采用阻塞式调用，容易影响录音、网络和播放任务。系统随后扩展为五通道配置，并使用独立 FreeRTOS 动作队列完成同步插值。开发中还发现未连接的触摸引脚会因悬空而反复触发动作，因此默认关闭触摸输入，并在关闭机器控制时清空动作队列和复位姿态。

修改后，PCA9685 通道0的 servo fl 80 和 servo fl 100 指令均能正常执行，动作只入队一次，说明通道0、动作队列和触摸输入保护能够协同工作。下一阶段将按照通道1至4、双舵机协同和五舵机整机的顺序扩展验证范围。

## 6.4 阶段结果与下一步计划

测试项 | 当前结果 | 阶段结论
单舵机台架 | 通道0正常运动，无尖叫 | 已完成通道0单机实验
五路动作代码 | 队列与插值编译通过 | 已完成代码验证；下一步开展多机实验
历史AI端到端 | 存在 PCM 上传、200响应和WAV下载日志 | 已形成历史链路证据
ASR small | 四段旧录音的非正式改善观察 | 为模型选型提供依据；下一步建立标准CER
GPT-SoVITS | 调试接口生成规范WAV | 已完成接口联调；下一步完成整机播放
连续对话v1 | 代码与编译完成 | 已完成代码与编译；下一步完成烧录验证

目前已经形成语音链路日志、通道0舵机运动记录、四段旧录音对比结果和 GPT-SoVITS 接口输出。下一步计划建立20～50条带人工标准文本的语料，统计唤醒、识别、端点检测和分阶段响应时间；硬件部分将依次完成其余通道、双舵机和五舵机协同实验，并记录峰值电流、温升、异常复位、动作噪声和机械卡滞情况。

# 7 结论

本文完成了毛绒陪伴机器人语音与动作系统的初步设计与实现。系统采用 ESP32-S3 与电脑端 AI bridge 分工：前者负责本地音频采集、唤醒、网络通信、播放和动作执行，后者负责 faster-whisper 识别、Ollama 对话和 TTS 合成。硬件方案明确了 INMP441、MAX98357A、PCA9685 和五路舵机的通信关系，并提出了2S电池经5V稳压后使用星形分支、舵机独立大电流支路和所有模块共地的成品供电结构。

在软件实现方面，系统已经具备端点检测录音、PCM 上传、结构化服务端返回、动态 WAV 下载播放、角色提示词加载和动作队列控制等能力。开发过程围绕三条主线展开：录音方式由固定时长改为端点检测，AI 服务链路增加状态日志和前验检查，动作控制由阻塞调用改为五通道队列与同步插值。ASR 模型、角色配置、TTS 格式和触摸输入也完成了相应调整。

当前语音链路和 PCA9685 通道0已经完成实际验证，五通道控制、连续对话和自定义音色具备代码与接口基础。下一阶段将完成五舵机与电源系统联调、连续对话固件烧录、标准 ASR 语料评价和 GPT-SoVITS 整机播放，并通过重复实验形成识别准确率、响应延迟、运行稳定性和陪伴体验的量化结论。

# 参考文献

[1] Espressif Systems. ESP32-S3 Series Datasheet[EB/OL]. https://www.espressif.com/sites/default/files/documentation/esp32-s3_datasheet_en.pdf.

[2] NXP Semiconductors. PCA9685 16-channel, 12-bit PWM Fm+ I2C-bus LED controller[EB/OL]. https://www.nxp.com/docs/en/data-sheet/PCA9685.pdf.

[3] TDK InvenSense. INMP441 High Accuracy Low Power Digital Output MEMS Microphone[EB/OL]. https://invensense.tdk.com/wp-content/uploads/2015/02/INMP441.pdf.

[4] Analog Devices. MAX98357A/MAX98357B PCM Input Class D Audio Power Amplifiers[EB/OL]. https://www.analog.com/media/en/technical-documentation/data-sheets/MAX98357A-MAX98357B.pdf.

[5] Radford A, Kim J W, Xu T, et al. Robust Speech Recognition via Large-Scale Weak Supervision[EB/OL]. arXiv:2212.04356, 2022.

[6] SYSTRAN. faster-whisper: Faster Whisper transcription with CTranslate2[EB/OL]. https://github.com/SYSTRAN/faster-whisper.

[7] Ollama. Ollama Documentation[EB/OL]. https://docs.ollama.com/.

[8] 毛绒治愈机器人PRP项目组. AI Bridge录音端点检测模块说明[Z]. 2026.

[9] 毛绒治愈机器人PRP项目组. 五舵机硬件集成与语音量化评估计划[Z]. 2026.

# 致谢

感谢指导教师在课题方向、系统设计和论文撰写方面给予的指导，感谢参与项目测试与讨论的同学提供意见，也感谢在硬件接线、语音录音和功能验证过程中给予帮助的人员。后续将继续完善实验记录，使本研究从可运行原型逐步发展为具有完整证据链的项目成果。

上海交通大学第 期PRP学生研究论文

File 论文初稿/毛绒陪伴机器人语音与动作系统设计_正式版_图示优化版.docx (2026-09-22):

项目编号：

本科生研究计划（PRP）研究论文

(第 期)

论文题目：_______________________________________

项目负责人：_________ 学院（系）： _______________

指导教师：_________ 学院（系）： _______________

参与学生：_______________________________________

项目执行时间：_____年_____月 至 _____年_____月

摘要

面向日常陪伴场景中用户对自然语音交互、情绪回应和具身动作反馈的需求，本文设计并实现了一套毛绒陪伴机器人语音与动作系统。系统以 ESP32-S3 为本地感知与执行终端，连接 INMP441 数字麦克风、MAX98357A 数字功放、扬声器、PCA9685 舵机驱动板及四个脚部舵机和一个尾巴舵机；电脑端 AI bridge 负责语音识别、对话生成和语音合成等计算量较大的任务。用户说出唤醒词后，设备进行端点检测录音，并通过 Wi-Fi 将 16 kHz PCM 语音上传至服务端；服务端依次完成 faster-whisper 语音识别、基于“糯糯”角色提示词的 Ollama 对话生成及 TTS 合成，返回回复文本、动作意图、耗时和音频地址。ESP32 下载并播放 WAV 音频，同时将动作意图投入 FreeRTOS 动作队列，由 PCA9685 输出五路 PWM 信号。本文还记录了录音端点检测、ASR 参数、角色提示词、TTS 回退、触摸悬空误触发和舵机供电等调试过程。当前已完成语音链路与单舵机通道0的实际验证；五舵机并发、连续对话新版固件和量化实验仍待进一步测试。

关键词：毛绒机器人，语音交互，ESP32-S3，动作控制，陪伴机器人

ABSTRACT

This study designs a voice and motion system for a plush companion robot. The ESP32-S3 is used as the local sensing and execution terminal, connected to an INMP441 digital microphone, a MAX98357A audio amplifier, a loudspeaker, a PCA9685 servo driver, four leg servos and one tail servo. A computer-side AI bridge performs speech recognition, dialogue generation and speech synthesis. After a wake word is detected, the device records speech through endpoint detection and uploads 16 kHz PCM audio to the server through Wi-Fi. The server performs faster-whisper speech recognition, Ollama-based dialogue generation with the Nuonuo persona prompt, and TTS synthesis. It then returns reply text, motion intent, timing information and an audio URL. The ESP32 downloads and plays the WAV audio while dispatching motion intents to a FreeRTOS queue. At present, the voice pipeline and servo channel 0 have been physically tested. Five-servo concurrent control, the latest continuous-dialogue firmware and quantitative evaluation remain to be completed.

KEY WORDS：plush robot, voice interaction, ESP32-S3, motion control, companion robot

# 1 绪论

## 1.1 研究背景

毛绒玩具具有柔软、低压力和容易亲近的外观特点，适合承载轻量化的陪伴交互。与只能播放固定音频的玩具相比，带有语音理解、回复语音和动作反馈能力的毛绒机器人，能够在用户表达疲惫、开心、焦虑或希望被陪伴时，给出相对自然的回应，并通过身体动作增强交互感受。

本项目以“糯糯”毛绒小龙为机器人形象，目标不是构建医疗诊断或心理治疗设备，而是实现一个可进行日常短对话、提供温和陪伴和做出简单肢体反馈的原型系统。系统设计需要同时处理嵌入式端本地唤醒与录音、无线音频传输、电脑端 AI 服务调用、语音播放、五路舵机控制以及移动供电条件下的稳定性。

## 1.2 研究目标与内容

本研究拟完成一个由嵌入式终端和电脑端 AI bridge 共同组成的语音交互系统。ESP32-S3 负责本地唤醒词检测、麦克风采集、网络通信、回复音频播放和动作执行；电脑端负责语音识别、大语言模型回复和语音合成。这样的分工避免将较大的 ASR、LLM 和 TTS 模型部署到资源有限的单片机中，同时保留机器人本地的声音输入、声音输出和动作能力。

本文围绕硬件结构、语音数据流、动作调度、个性化配置和测试方法展开。研究重点包括：设计五路舵机的供电和控制方式；实现唤醒、端点检测录音、PCM 上传、ASR、LLM、TTS、WAV 下载播放和动作执行链路；将角色提示词与业务代码解耦；建立对识别准确率、响应耗时和动作稳定性的测试方案。

## 1.3 研究范围与证据边界

本文重点讨论原型系统的软硬件设计、实现过程和测试方法。当前代码中已经配置了前左、前右、后左、后右和尾巴五个舵机通道，并完成了动作队列与同步插值逻辑；但实际硬件验证目前仅覆盖 PCA9685 通道0的一只 SG90 舵机。因此，文中将严格区分“五路控制代码已实现”和“五舵机整机已稳定运行”。

当前服务端已配置 faster-whisper small 模型、Ollama qwen2.5:3b 模型和 Windows SAPI TTS；GPT-SoVITS 已完成单独接口联调，但尚未形成其在 ESP32 整机上的稳定播放证据。连续对话的最新“30 秒无语音退出、最多8轮”固件已通过编译，尚未烧录实测。后续章节中的状态描述均以“设计计划、已写入代码、已编译、已烧录、已实测、已有量化数据”作为判断依据。

# 2 系统总体方案

## 2.1 四层架构

系统按职责分为四层。用户交互层负责用户说话、唤醒机器人、收听回复和观察动作；设备感知与执行层负责音频采集、播放和舵机输出；通信与业务调度层负责 Wi-Fi、HTTP、PCM/WAV 处理和 JSON 结果汇总；AI 能力层负责语音识别、对话生成、角色约束、语音合成和动作意图生成。供电系统不属于其中单独一层，而是支撑设备层全部模块的基础设施。


图2-1 毛绒陪伴机器人四层总体架构

## 2.2 终端与服务端分工

ESP32-S3 侧的任务强调低时延和与物理设备直接相连，包括 WakeNet 本地唤醒、INMP441 音频读取、端点检测、HTTP 上传、WAV 音频播放以及 PCA9685 动作控制。电脑端服务采用 FastAPI 组织 AI bridge，接收原始 PCM 后转换为 WAV，依次调用 ASR、对话服务和 TTS 服务，并以 JSON 返回识别文字、回复、动作、音频地址和耗时。该方式使服务端模型可以独立替换，ESP32 不需要因更换 ASR、LLM 或 TTS 后端而重新设计协议。

## 2.3 已实现状态

子系统 | 当前实现 | 证据状态
本地唤醒 | WakeNet9 与“你好小智”模型 | 已写入代码；历史使用
录音 | 端点检测、噪声基线、pre-roll、静音结束 | 已写入代码；待系统量化
AI bridge | PCM 上传、ASR、Ollama、TTS、JSON 返回 | 已写入代码；历史端到端日志
连续对话 | 最多8轮、30秒无语音退出 | 已编译，未烧录实测
动作控制 | 五路配置、队列、同步插值 | 已编译；通道0单机实测
五舵机整机 | 并发、负载和温升 | 待连接与测试

# 3 硬件系统设计

## 3.1 硬件组成与职责

硬件部分以 ESP32-S3 为核心。INMP441 是数字 MEMS 麦克风，使用 I2S 输出音频数据；MAX98357A 是 I2S 数字功放，将 ESP32 输出的数字音频转换为可驱动喇叭的信号；PCA9685 是 16 通道 PWM 驱动器，通过 I2C 接收控制命令后输出舵机脉冲。原型方案使用 PCA9685 的前五个通道分别连接四个脚部舵机和一个尾巴舵机，便于后续扩展和独立校准。

模块 | 作用 | 当前状态
ESP32-S3 | 本地语音、Wi-Fi、播放和动作调度 | 当前统一工程主控
INMP441 | 采集用户语音并输出 I2S 数据 | GPIO 已由代码固定
MAX98357A+喇叭 | 播放欢迎音和服务端回复音频 | 代码支持 WAV 下载与播放
PCA9685 | 输出五路舵机 PWM | 通道0已实际验证
SG90 或后续选型舵机 | 脚部和尾巴姿态动作 | 其余四路待验证
2S电池、保护、降压 | 移动供电与电压转换 | 成品方案待整机验证

## 3.2 GPIO 与通信连接

当前固件将 INMP441 的 WS、SCK 和 SD 分别固定为 GPIO4、GPIO5 和 GPIO6；MAX98357A 的 BCLK、LRC 和 DIN 分别使用 GPIO15、GPIO16 和 GPIO7。PCA9685 通过 I2C 与 ESP32-S3 通信，GPIO1 为 SDA，GPIO2 为 SCL，I2C 时钟设为100 kHz。该分配以当前代码为依据，不能沿用早期单舵机直连 GPIO18 的示例。GPIO18 对应的旧 ServoController 文件仍保留在工程中，但不属于当前 PCA9685 五舵机方案。

ESP32-S3 引脚 | 连接模块引脚 | 通信/用途
GPIO4 | INMP441 WS/LRCLK | I2S 输入字选择
GPIO5 | INMP441 SCK/BCLK | I2S 输入位时钟
GPIO6 | INMP441 SD | I2S 输入数据
GPIO7 | MAX98357A DIN | I2S 输出数据
GPIO15 | MAX98357A BCLK | I2S 输出位时钟
GPIO16 | MAX98357A LRC | I2S 输出左右声道时钟
GPIO1 | PCA9685 SDA | I2C 数据
GPIO2 | PCA9685 SCL | I2C 时钟

## 3.3 五路舵机与安全限位

PCA9685 通道0至4依次分配给前左、前右、后左、后右和尾巴。当前脚部保守角度范围为70°至110°，尾巴为60°至120°，主页均为90°。这些数值来自空载台架安全限制，尚未根据实际毛绒骨架、舵机安装方向和机械干涉完成标定。软件对于超出范围的串口命令直接拒绝，以减少初期测试中撞限位和卡滞的风险。

PCA9685通道 | 肢体 | 当前范围 | 状态
0 | 前左 | 70°～110° | 已单机实测
1 | 前右 | 70°～110° | 待测
2 | 后左 | 70°～110° | 待测
3 | 后右 | 70°～110° | 待测
4 | 尾巴 | 60°～120° | 待测

## 3.4 供电与共地设计

PCA9685 板上的 VCC 和 V+ 必须区分。VCC 用于驱动芯片的逻辑供电，应接 ESP32 的3.3V；V+ 是舵机供电排，应连接外部稳压5V。舵机的信号电压需要以 ESP32 为参考，因此 ESP32、PCA9685 和外部5V电源必须共地。共地不是让舵机从 ESP32 取电，而是建立统一的信号参考电位。

五个舵机启动、换向或受阻时可能出现较大的瞬时电流。若让它们通过 ESP32 开发板的5V或3.3V引脚供电，可能造成板载稳压器过载、压降或复位，也会把电机噪声带入音频链路。因此，成品设计采用2S电池经过保护、保险丝和总开关后进入5V大电流稳压模块，再以星形分支分别供给 PCA9685 V+、ESP32的5V/VIN和音频模块。舵机支路入口应配置大容量低 ESR 电容，电源线需采用能承载电流的线材；普通杜邦线和面包板不适合承载整机舵机电流。

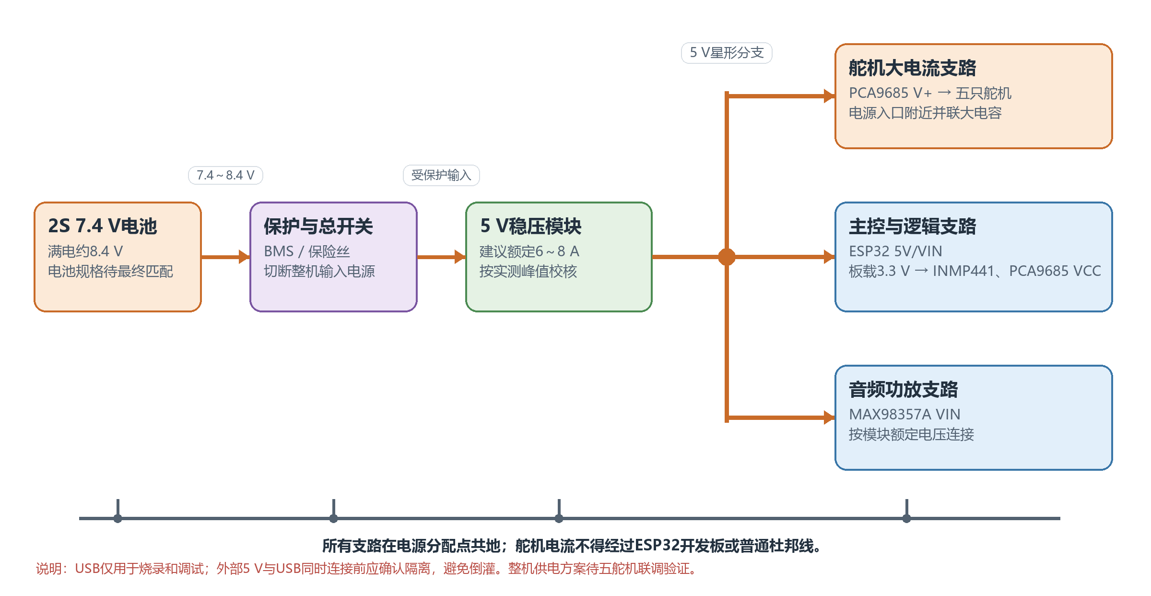
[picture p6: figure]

图3-1 成品供电结构（设计方案，待整机验证）

# 4 软件系统与交互流程

## 4.1 ESP32 语音状态机

设备上电后初始化音频输入输出、唤醒模型、命令词模型、Wi-Fi 和动作模块，并进入等待唤醒状态。检测到“你好小智”后，系统播放本地欢迎音。若 AI bridge 已连接，则进入端点检测录音；若网络或服务不可用，则保留本地命令词模式作为回退。该回退机制最初只表现为静默切换，容易被误认为端点检测故障，后续已增加 Wi-Fi 状态、服务器地址和 AI bridge ready 状态日志。

端点检测先采集环境噪声估计 noise_floor，然后在等待开口阶段维护短时 pre-roll 环形缓冲。当 RMS 连续超过动态开始阈值达到确认时间后，系统把 pre-roll 写入正式录音并进入录音状态；在达到最短录音时长后，连续静音达到设定时间则结束；达到最长时长时也会强制结束。录音结果是16 kHz、16 bit、单声道 PCM。

## 4.2 AI bridge 调度

ESP32 使用 HTTP POST 上传 PCM，并在请求头中传递采样率和音频格式。FastAPI 服务保存原始 PCM，同时进行音量归一化后写入 WAV。服务端顺序调用 faster-whisper、对话服务和 TTS 服务，最后返回 recognized_text、reply_text、reply_emotion、motion、audio_url、timings_ms 等字段。ASR、LLM 和 TTS 存在数据依赖，因此当前链路以顺序调用为主。

当前 ASR 使用 faster-whisper small、CPU int8、beam_size=5、best_of=5，并关闭跨片段文本条件；识别结果使用 OpenCC 转换为简体。初步的四段旧录音复查显示 small 模型在部分错句上优于原 tiny 模型，但旧样本没有完整人工标准文本，不能据此报告正式字错误率。服务端提供 benchmark_asr.py 脚本，后续可对带参考文本的20～50条语料计算 CER、整句正确率和耗时。

## 4.3 回复生成、TTS 与动作意图

对话服务默认调用 Ollama 中的 qwen2.5:3b 模型。角色设定存放在独立的 nuonuo_v1.txt 文件中，业务代码通过配置读取，使机器人名称、表达方式和安全边界能够在不修改对话逻辑的情况下切换。模型被要求返回 reply_text、style、emotion 和 motion 字段，服务端再根据用户输入校正情绪与动作，避免负面情绪被误配为 happy。若 Ollama 不可用或返回解析失败，服务端使用规则回复兜底并标记状态。

TTS 服务提供 Windows SAPI 和 GPT-SoVITS 两个后端。所有输出在服务端统一为 ESP32 可播放的16 kHz、16 bit、单声道 WAV。当前后台 AI bridge 默认采用 Windows SAPI；GPT-SoVITS 已在调试接口生成过规范 WAV，但未完成当前整机的持续联调。ESP32 下载完整 WAV 后解析 data 区块并通过 I2S 送往 MAX98357A 播放。

## 4.4 动作队列与同步插值

服务端 motion 字段支持 happy、shy、comfort、curious 和 none。ESP32 在机器控制开关开启时把相应意图投递到长度为8的 FreeRTOS 队列。动作任务从队列中取出命令，按照目标姿态和当前姿态之间的最大角度差确定插值步数，再同步更新五个通道，避免网络、录音或播放任务直接执行长时间阻塞动作。当前 comfort 和 curious 在执行端共用 curious 动作，属于第一版动作映射，后续应结合整机外观和用户体验继续细化。

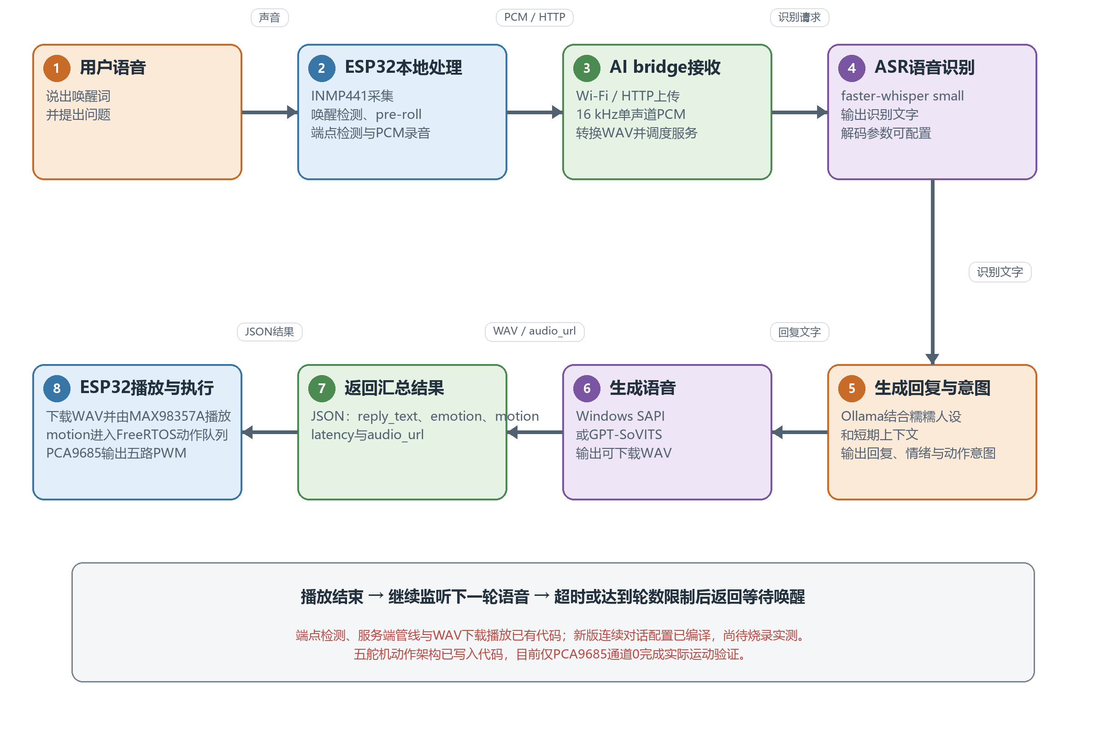
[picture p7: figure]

图4-1 语音交互与动作执行数据流

# 5 个性化设计

## 5.1 角色与回复风格

当前“糯糯”人设描述其为温暖、活泼、略带傲娇的毛绒小龙。提示词同时约束回复应使用简体中文、尽量短、适合语音播放，不进行医学诊断或承诺治疗效果；当出现明显危险、自伤或急症内容时，应鼓励用户寻求现实中的可信任人员或专业帮助。服务端当前提供 cute 和 encourage 两种情境风格，并保留最近四轮对话作为短期上下文。

## 5.2 可配置项目

可配置内容 | 配置位置 | 当前状态
角色名称与提示词 | server/prompts 与环境变量 | 已提供入口
LLM模型、超时与回复风格 | server_config.py / 环境变量 | 已提供入口
ASR模型、beam、best_of、热词 | server_config.py / 环境变量 | 已提供入口；热词默认关闭
TTS后端、参考音频与语言 | server_config.py / 环境变量 | 已提供入口
端点检测阈值与会话时间 | main/network_config.h | 已提供入口
舵机通道、角度范围与主页 | main/robot_config.h | 已提供入口，待机械校准
触摸输入 | main/robot_config.h | 代码预留，默认关闭

需要注意的是，配置入口不等于已经完成效果验证。例如，GPT-SoVITS 后端可由配置启用，但当前后台服务尚未运行该 API；触摸输入已有 GPIO 和动作映射，但未接硬件时默认关闭。论文中应将这些内容写为“可配置能力”或“待验证扩展”，而不能表述为成品功能。

# 6 开发过程、测试与讨论

## 6.1 录音和网络链路的迭代

项目早期采用固定5秒录音。该方式在短句场景中会引入额外静音和等待，而长句或停顿场景又可能出现截断。为此，固件保留固定时长函数作为回退，并新增端点检测函数，通过环境噪声基线、动态开始/停止阈值、80 ms 开口确认、300 ms pre-roll、最短录音时长和连续静音结束判定控制上传边界。该功能已经写入当前代码；需要在短句、长句、停顿和不开口场景下进一步采集串口日志和录音样本，才能形成端点完整率结论。

一次测试中，欢迎音播放后系统直接进入本地命令词模式，表面现象像是端点检测没有执行。排查后发现根因是 ai_bridge_ready 为 false 时触发了静默回退，且旧日志在 ready 判断前就打印了“准备录音”。后续修改为每次唤醒前检查 Wi-Fi 和 AI bridge 状态，并输出服务器地址和失败原因。该问题说明联网系统需要可观测性，不能仅依赖静默回退。

## 6.2 ASR、回复与TTS的迭代

ASR 从 tiny 调整为 small 后，解码参数修改为 beam_size=5、best_of=5，关闭跨片段文本条件，并增加繁体转简体。完整提示词和过强热词曾在短而含糊的录音中引发幻听，因此当前默认关闭，仅保留受控实验配置入口。非正式旧录音复查显示 small 模型对部分结果有改善，热启动单条识别约1.6～1.8秒；这只是开发观察，不能替代标准语料的统计实验。

回复生成方面，项目从规则话术逐步增加 Ollama 本地模型、角色提示词、短期上下文、情绪字段和动作字段。人设文件从业务代码拆出后，能够在不重写服务逻辑的情况下切换机器人形象。TTS 方面，Windows SAPI 被保留为稳定回退；GPT-SoVITS 适配了 api_v2 参数和 WAV 规范化，单独调试接口已成功生成可识别的16 kHz WAV，但当前整机端到端效果仍待验证。

## 6.3 动作与硬件问题的迭代

为适配四脚加尾巴，动作层从早期的少路、阻塞式控制调整为五通道配置和独立 FreeRTOS 动作任务。公开动作函数仅负责入队，执行任务负责插值和 PWM 写入。统一工程的五路版本已经编译，且 v2 固件曾成功烧录；实际复测中，GPIO8、GPIO9、GPIO10 未连接的触摸输入处于悬空状态，持续误触发动作并占满队列，导致正常串口舵机命令看似无效。修复方案是将 TOUCH_INPUTS_ENABLED 默认设为 false，并使关闭机器控制时清空待执行动作和请求复位。

修复后，用户实际测试了通道0的 servo fl 80 和 servo fl 100 指令，确认动作只入队一次且舵机运动符合预期。这证明了统一工程中 PCA9685 通道0、动作队列和悬空触摸修复的可用性，但不证明其余四通道、组合动作或五机大电流供电已通过。

## 6.4 当前测试结果与待补实验

测试项 | 当前结果 | 论文表述边界
单舵机台架 | 通道0正常运动，无尖叫 | 已实测；仅单机
五路动作代码 | 队列与插值编译通过 | 不可写成五机已稳定运行
历史AI端到端 | 存在 PCM 上传、200响应和WAV下载日志 | 证明历史链路通，不代表最新固件
ASR small | 四段旧录音的非正式改善观察 | 不可报告正式CER
GPT-SoVITS | 调试接口生成规范WAV | 当前整机联调待完成
连续对话v1 | 代码与编译完成 | 尚未烧录实测

后续实验应首先建立带人工标准文本的20～50条语料，在安静和普通室内噪声、20 cm和50 cm距离下记录唤醒成功率、误唤醒率、CER、整句正确率和端点完整率。响应速度应记录说话结束、上传完成、ASR完成、LLM完成、TTS完成、下载完成、播放开始和动作开始时间，并报告P50与P90。硬件部分应逐通道验证1至4，再从两机并发逐步扩展到五机，记录峰值电流、异常复位、温升、动作噪声和机械卡滞情况。

# 7 结论

本文完成了毛绒陪伴机器人语音与动作系统的初步设计与实现。系统采用 ESP32-S3 与电脑端 AI bridge 分工：前者负责本地音频采集、唤醒、网络通信、播放和动作执行，后者负责 faster-whisper 识别、Ollama 对话和 TTS 合成。硬件方案明确了 INMP441、MAX98357A、PCA9685 和五路舵机的通信关系，并提出了2S电池经5V稳压后使用星形分支、舵机独立大电流支路和所有模块共地的成品供电结构。

在软件实现方面，系统已具备端点检测录音、PCM 上传、结构化服务端返回、动态 WAV 下载播放、角色提示词加载和动作队列控制等能力。开发过程中针对固定时长录音、AI bridge 静默回退、ASR 幻听、角色一致性、TTS 格式、触摸悬空误触发和阻塞式动作等问题进行了多轮修改。当前已完成单舵机通道0的实际验证，并保留了历史语音端到端日志。

本项目仍处于原型迭代阶段。后续需要完成五路舵机与电源系统的实测、连续对话最新版固件的烧录、端点检测的系统化场景测试、标准 ASR 语料评估、GPT-SoVITS 整机联调及用户体验评价。只有在获得重复测试记录后，才能对识别准确率、延迟、稳定性和陪伴体验形成量化结论。

# 参考文献

[1] Espressif Systems. ESP32-S3 Series Datasheet[EB/OL]. https://www.espressif.com/sites/default/files/documentation/esp32-s3_datasheet_en.pdf.

[2] NXP Semiconductors. PCA9685 16-channel, 12-bit PWM Fm+ I2C-bus LED controller[EB/OL]. https://www.nxp.com/docs/en/data-sheet/PCA9685.pdf.

[3] TDK InvenSense. INMP441 High Accuracy Low Power Digital Output MEMS Microphone[EB/OL]. https://invensense.tdk.com/wp-content/uploads/2015/02/INMP441.pdf.

[4] Analog Devices. MAX98357A/MAX98357B PCM Input Class D Audio Power Amplifiers[EB/OL]. https://www.analog.com/media/en/technical-documentation/data-sheets/MAX98357A-MAX98357B.pdf.

[5] Radford A, Kim J W, Xu T, et al. Robust Speech Recognition via Large-Scale Weak Supervision[EB/OL]. arXiv:2212.04356, 2022.

[6] SYSTRAN. faster-whisper: Faster Whisper transcription with CTranslate2[EB/OL]. https://github.com/SYSTRAN/faster-whisper.

[7] Ollama. Ollama Documentation[EB/OL]. https://docs.ollama.com/.

[8] 毛绒治愈机器人PRP项目组. AI Bridge录音端点检测模块说明[Z]. 2026.

[9] 毛绒治愈机器人PRP项目组. 五舵机硬件集成与语音量化评估计划[Z]. 2026.

# 致谢

感谢指导教师在课题方向、系统设计和论文撰写方面给予的指导，感谢参与项目测试与讨论的同学提供意见，也感谢在硬件接线、语音录音和功能验证过程中给予帮助的人员。后续将继续完善实验记录，使本研究从可运行原型逐步发展为具有完整证据链的项目成果。

上海交通大学第 期PRP学生研究论文

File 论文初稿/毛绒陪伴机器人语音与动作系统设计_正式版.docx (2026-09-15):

项目编号：

本科生研究计划（PRP）研究论文

(第 期)

论文题目：_______________________________________

项目负责人：_________ 学院（系）： _______________

指导教师：_________ 学院（系）： _______________

参与学生：_______________________________________

项目执行时间：_____年_____月 至 _____年_____月

摘要

面向日常陪伴场景中用户对自然语音交互、情绪回应和具身动作反馈的需求，本文设计并实现了一套毛绒陪伴机器人语音与动作系统。系统以 ESP32-S3 为本地感知与执行终端，连接 INMP441 数字麦克风、MAX98357A 数字功放、扬声器、PCA9685 舵机驱动板及四个脚部舵机和一个尾巴舵机；电脑端 AI bridge 负责语音识别、对话生成和语音合成等计算量较大的任务。用户说出唤醒词后，设备进行端点检测录音，并通过 Wi-Fi 将 16 kHz PCM 语音上传至服务端；服务端依次完成 faster-whisper 语音识别、基于“糯糯”角色提示词的 Ollama 对话生成及 TTS 合成，返回回复文本、动作意图、耗时和音频地址。ESP32 下载并播放 WAV 音频，同时将动作意图投入 FreeRTOS 动作队列，由 PCA9685 输出五路 PWM 信号。本文还记录了录音端点检测、ASR 参数、角色提示词、TTS 回退、触摸悬空误触发和舵机供电等调试过程。当前已完成语音链路与单舵机通道0的实际验证；五舵机并发、连续对话新版固件和量化实验仍待进一步测试。

关键词：毛绒机器人，语音交互，ESP32-S3，动作控制，陪伴机器人

ABSTRACT

This study designs a voice and motion system for a plush companion robot. The ESP32-S3 is used as the local sensing and execution terminal, connected to an INMP441 digital microphone, a MAX98357A audio amplifier, a loudspeaker, a PCA9685 servo driver, four leg servos and one tail servo. A computer-side AI bridge performs speech recognition, dialogue generation and speech synthesis. After a wake word is detected, the device records speech through endpoint detection and uploads 16 kHz PCM audio to the server through Wi-Fi. The server performs faster-whisper speech recognition, Ollama-based dialogue generation with the Nuonuo persona prompt, and TTS synthesis. It then returns reply text, motion intent, timing information and an audio URL. The ESP32 downloads and plays the WAV audio while dispatching motion intents to a FreeRTOS queue. At present, the voice pipeline and servo channel 0 have been physically tested. Five-servo concurrent control, the latest continuous-dialogue firmware and quantitative evaluation remain to be completed.

KEY WORDS：plush robot, voice interaction, ESP32-S3, motion control, companion robot

# 1 绪论

## 1.1 研究背景

毛绒玩具具有柔软、低压力和容易亲近的外观特点，适合承载轻量化的陪伴交互。与只能播放固定音频的玩具相比，带有语音理解、回复语音和动作反馈能力的毛绒机器人，能够在用户表达疲惫、开心、焦虑或希望被陪伴时，给出相对自然的回应，并通过身体动作增强交互感受。

本项目以“糯糯”毛绒小龙为机器人形象，目标不是构建医疗诊断或心理治疗设备，而是实现一个可进行日常短对话、提供温和陪伴和做出简单肢体反馈的原型系统。系统设计需要同时处理嵌入式端本地唤醒与录音、无线音频传输、电脑端 AI 服务调用、语音播放、五路舵机控制以及移动供电条件下的稳定性。

## 1.2 研究目标与内容

本研究拟完成一个由嵌入式终端和电脑端 AI bridge 共同组成的语音交互系统。ESP32-S3 负责本地唤醒词检测、麦克风采集、网络通信、回复音频播放和动作执行；电脑端负责语音识别、大语言模型回复和语音合成。这样的分工避免将较大的 ASR、LLM 和 TTS 模型部署到资源有限的单片机中，同时保留机器人本地的声音输入、声音输出和动作能力。

本文围绕硬件结构、语音数据流、动作调度、个性化配置和测试方法展开。研究重点包括：设计五路舵机的供电和控制方式；实现唤醒、端点检测录音、PCM 上传、ASR、LLM、TTS、WAV 下载播放和动作执行链路；将角色提示词与业务代码解耦；建立对识别准确率、响应耗时和动作稳定性的测试方案。

## 1.3 研究范围与证据边界

本文重点讨论原型系统的软硬件设计、实现过程和测试方法。当前代码中已经配置了前左、前右、后左、后右和尾巴五个舵机通道，并完成了动作队列与同步插值逻辑；但实际硬件验证目前仅覆盖 PCA9685 通道0的一只 SG90 舵机。因此，文中将严格区分“五路控制代码已实现”和“五舵机整机已稳定运行”。

当前服务端已配置 faster-whisper small 模型、Ollama qwen2.5:3b 模型和 Windows SAPI TTS；GPT-SoVITS 已完成单独接口联调，但尚未形成其在 ESP32 整机上的稳定播放证据。连续对话的最新“30 秒无语音退出、最多8轮”固件已通过编译，尚未烧录实测。后续章节中的状态描述均以“设计计划、已写入代码、已编译、已烧录、已实测、已有量化数据”作为判断依据。

# 2 系统总体方案

## 2.1 四层架构

系统按职责分为四层。用户交互层负责用户说话、唤醒机器人、收听回复和观察动作；设备感知与执行层负责音频采集、播放和舵机输出；通信与业务调度层负责 Wi-Fi、HTTP、PCM/WAV 处理和 JSON 结果汇总；AI 能力层负责语音识别、对话生成、角色约束、语音合成和动作意图生成。供电系统不属于其中单独一层，而是支撑设备层全部模块的基础设施。

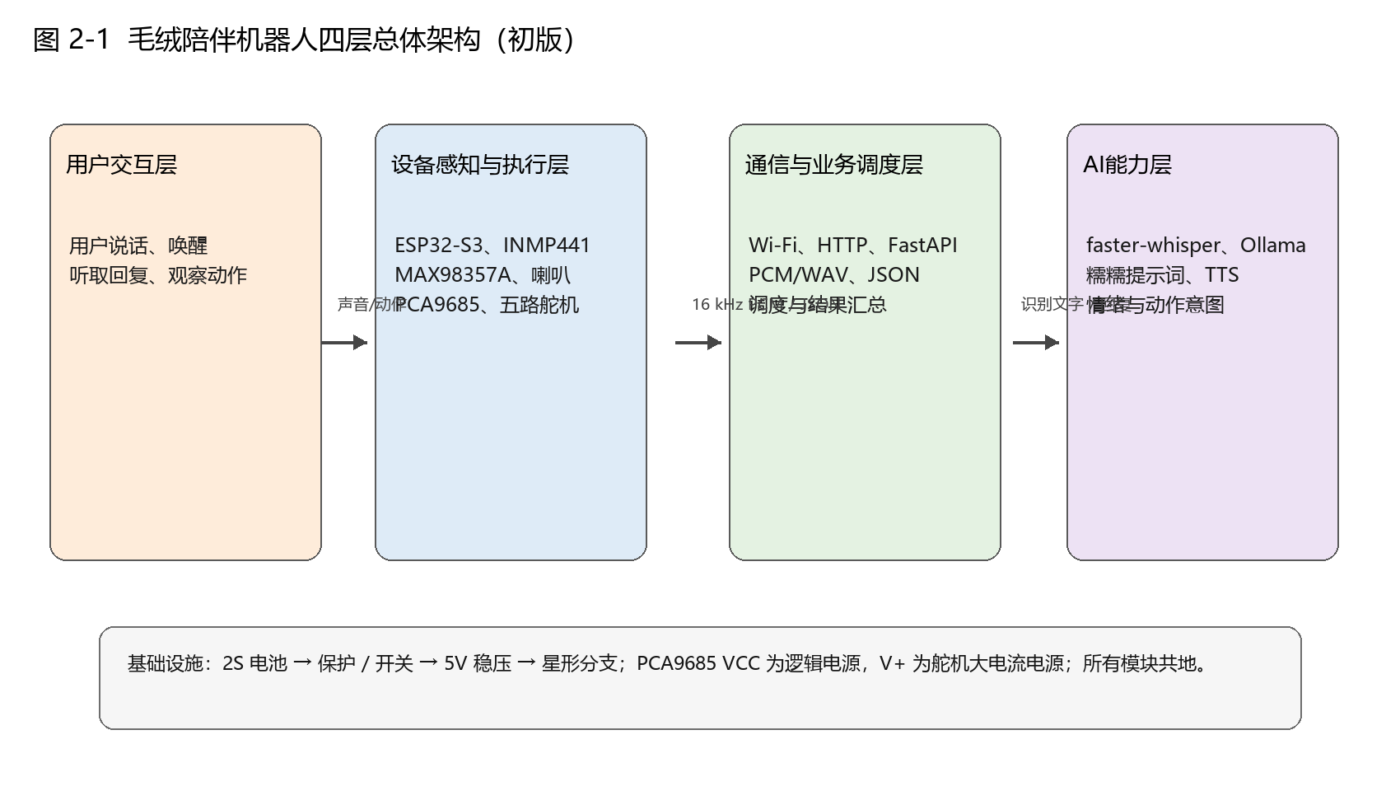
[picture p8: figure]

图2-1 毛绒陪伴机器人四层总体架构

## 2.2 终端与服务端分工

ESP32-S3 侧的任务强调低时延和与物理设备直接相连，包括 WakeNet 本地唤醒、INMP441 音频读取、端点检测、HTTP 上传、WAV 音频播放以及 PCA9685 动作控制。电脑端服务采用 FastAPI 组织 AI bridge，接收原始 PCM 后转换为 WAV，依次调用 ASR、对话服务和 TTS 服务，并以 JSON 返回识别文字、回复、动作、音频地址和耗时。该方式使服务端模型可以独立替换，ESP32 不需要因更换 ASR、LLM 或 TTS 后端而重新设计协议。

## 2.3 已实现状态

子系统 | 当前实现 | 证据状态
本地唤醒 | WakeNet9 与“你好小智”模型 | 已写入代码；历史使用
录音 | 端点检测、噪声基线、pre-roll、静音结束 | 已写入代码；待系统量化
AI bridge | PCM 上传、ASR、Ollama、TTS、JSON 返回 | 已写入代码；历史端到端日志
连续对话 | 最多8轮、30秒无语音退出 | 已编译，未烧录实测
动作控制 | 五路配置、队列、同步插值 | 已编译；通道0单机实测
五舵机整机 | 并发、负载和温升 | 待连接与测试

# 3 硬件系统设计

## 3.1 硬件组成与职责

硬件部分以 ESP32-S3 为核心。INMP441 是数字 MEMS 麦克风，使用 I2S 输出音频数据；MAX98357A 是 I2S 数字功放，将 ESP32 输出的数字音频转换为可驱动喇叭的信号；PCA9685 是 16 通道 PWM 驱动器，通过 I2C 接收控制命令后输出舵机脉冲。原型方案使用 PCA9685 的前五个通道分别连接四个脚部舵机和一个尾巴舵机，便于后续扩展和独立校准。

模块 | 作用 | 当前状态
ESP32-S3 | 本地语音、Wi-Fi、播放和动作调度 | 当前统一工程主控
INMP441 | 采集用户语音并输出 I2S 数据 | GPIO 已由代码固定
MAX98357A+喇叭 | 播放欢迎音和服务端回复音频 | 代码支持 WAV 下载与播放
PCA9685 | 输出五路舵机 PWM | 通道0已实际验证
SG90 或后续选型舵机 | 脚部和尾巴姿态动作 | 其余四路待验证
2S电池、保护、降压 | 移动供电与电压转换 | 成品方案待整机验证

## 3.2 GPIO 与通信连接

当前固件将 INMP441 的 WS、SCK 和 SD 分别固定为 GPIO4、GPIO5 和 GPIO6；MAX98357A 的 BCLK、LRC 和 DIN 分别使用 GPIO15、GPIO16 和 GPIO7。PCA9685 通过 I2C 与 ESP32-S3 通信，GPIO1 为 SDA，GPIO2 为 SCL，I2C 时钟设为100 kHz。该分配以当前代码为依据，不能沿用早期单舵机直连 GPIO18 的示例。GPIO18 对应的旧 ServoController 文件仍保留在工程中，但不属于当前 PCA9685 五舵机方案。

ESP32-S3 引脚 | 连接模块引脚 | 通信/用途
GPIO4 | INMP441 WS/LRCLK | I2S 输入字选择
GPIO5 | INMP441 SCK/BCLK | I2S 输入位时钟
GPIO6 | INMP441 SD | I2S 输入数据
GPIO7 | MAX98357A DIN | I2S 输出数据
GPIO15 | MAX98357A BCLK | I2S 输出位时钟
GPIO16 | MAX98357A LRC | I2S 输出左右声道时钟
GPIO1 | PCA9685 SDA | I2C 数据
GPIO2 | PCA9685 SCL | I2C 时钟

## 3.3 五路舵机与安全限位

PCA9685 通道0至4依次分配给前左、前右、后左、后右和尾巴。当前脚部保守角度范围为70°至110°，尾巴为60°至120°，主页均为90°。这些数值来自空载台架安全限制，尚未根据实际毛绒骨架、舵机安装方向和机械干涉完成标定。软件对于超出范围的串口命令直接拒绝，以减少初期测试中撞限位和卡滞的风险。

PCA9685通道 | 肢体 | 当前范围 | 状态
0 | 前左 | 70°～110° | 已单机实测
1 | 前右 | 70°～110° | 待测
2 | 后左 | 70°～110° | 待测
3 | 后右 | 70°～110° | 待测
4 | 尾巴 | 60°～120° | 待测

## 3.4 供电与共地设计

PCA9685 板上的 VCC 和 V+ 必须区分。VCC 用于驱动芯片的逻辑供电，应接 ESP32 的3.3V；V+ 是舵机供电排，应连接外部稳压5V。舵机的信号电压需要以 ESP32 为参考，因此 ESP32、PCA9685 和外部5V电源必须共地。共地不是让舵机从 ESP32 取电，而是建立统一的信号参考电位。

五个舵机启动、换向或受阻时可能出现较大的瞬时电流。若让它们通过 ESP32 开发板的5V或3.3V引脚供电，可能造成板载稳压器过载、压降或复位，也会把电机噪声带入音频链路。因此，成品设计采用2S电池经过保护、保险丝和总开关后进入5V大电流稳压模块，再以星形分支分别供给 PCA9685 V+、ESP32的5V/VIN和音频模块。舵机支路入口应配置大容量低 ESR 电容，电源线需采用能承载电流的线材；普通杜邦线和面包板不适合承载整机舵机电流。

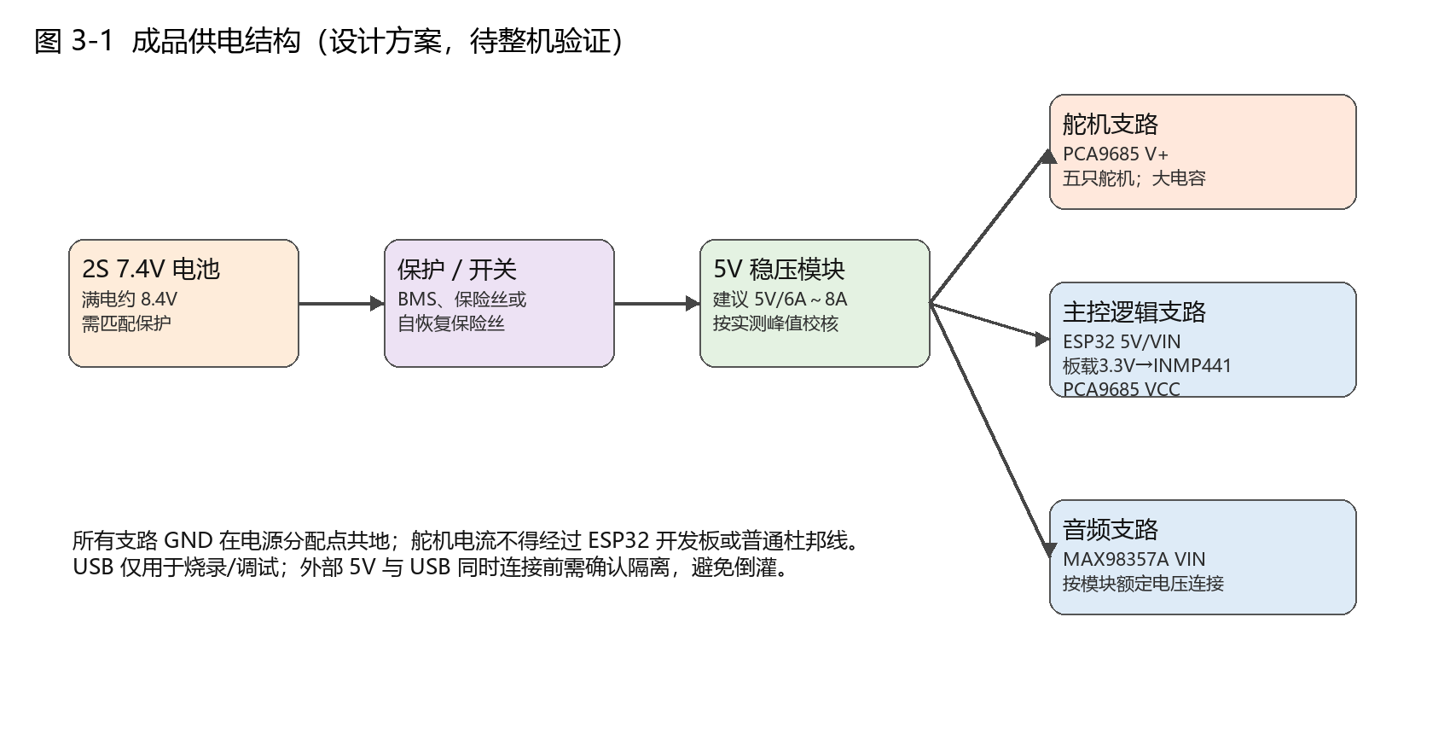
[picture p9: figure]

图3-1 成品供电结构（设计方案，待整机验证）

# 4 软件系统与交互流程

## 4.1 ESP32 语音状态机

设备上电后初始化音频输入输出、唤醒模型、命令词模型、Wi-Fi 和动作模块，并进入等待唤醒状态。检测到“你好小智”后，系统播放本地欢迎音。若 AI bridge 已连接，则进入端点检测录音；若网络或服务不可用，则保留本地命令词模式作为回退。该回退机制最初只表现为静默切换，容易被误认为端点检测故障，后续已增加 Wi-Fi 状态、服务器地址和 AI bridge ready 状态日志。

端点检测先采集环境噪声估计 noise_floor，然后在等待开口阶段维护短时 pre-roll 环形缓冲。当 RMS 连续超过动态开始阈值达到确认时间后，系统把 pre-roll 写入正式录音并进入录音状态；在达到最短录音时长后，连续静音达到设定时间则结束；达到最长时长时也会强制结束。录音结果是16 kHz、16 bit、单声道 PCM。

## 4.2 AI bridge 调度

ESP32 使用 HTTP POST 上传 PCM，并在请求头中传递采样率和音频格式。FastAPI 服务保存原始 PCM，同时进行音量归一化后写入 WAV。服务端顺序调用 faster-whisper、对话服务和 TTS 服务，最后返回 recognized_text、reply_text、reply_emotion、motion、audio_url、timings_ms 等字段。ASR、LLM 和 TTS 存在数据依赖，因此当前链路以顺序调用为主。

当前 ASR 使用 faster-whisper small、CPU int8、beam_size=5、best_of=5，并关闭跨片段文本条件；识别结果使用 OpenCC 转换为简体。初步的四段旧录音复查显示 small 模型在部分错句上优于原 tiny 模型，但旧样本没有完整人工标准文本，不能据此报告正式字错误率。服务端提供 benchmark_asr.py 脚本，后续可对带参考文本的20～50条语料计算 CER、整句正确率和耗时。

## 4.3 回复生成、TTS 与动作意图

对话服务默认调用 Ollama 中的 qwen2.5:3b 模型。角色设定存放在独立的 nuonuo_v1.txt 文件中，业务代码通过配置读取，使机器人名称、表达方式和安全边界能够在不修改对话逻辑的情况下切换。模型被要求返回 reply_text、style、emotion 和 motion 字段，服务端再根据用户输入校正情绪与动作，避免负面情绪被误配为 happy。若 Ollama 不可用或返回解析失败，服务端使用规则回复兜底并标记状态。

TTS 服务提供 Windows SAPI 和 GPT-SoVITS 两个后端。所有输出在服务端统一为 ESP32 可播放的16 kHz、16 bit、单声道 WAV。当前后台 AI bridge 默认采用 Windows SAPI；GPT-SoVITS 已在调试接口生成过规范 WAV，但未完成当前整机的持续联调。ESP32 下载完整 WAV 后解析 data 区块并通过 I2S 送往 MAX98357A 播放。

## 4.4 动作队列与同步插值

服务端 motion 字段支持 happy、shy、comfort、curious 和 none。ESP32 在机器控制开关开启时把相应意图投递到长度为8的 FreeRTOS 队列。动作任务从队列中取出命令，按照目标姿态和当前姿态之间的最大角度差确定插值步数，再同步更新五个通道，避免网络、录音或播放任务直接执行长时间阻塞动作。当前 comfort 和 curious 在执行端共用 curious 动作，属于第一版动作映射，后续应结合整机外观和用户体验继续细化。

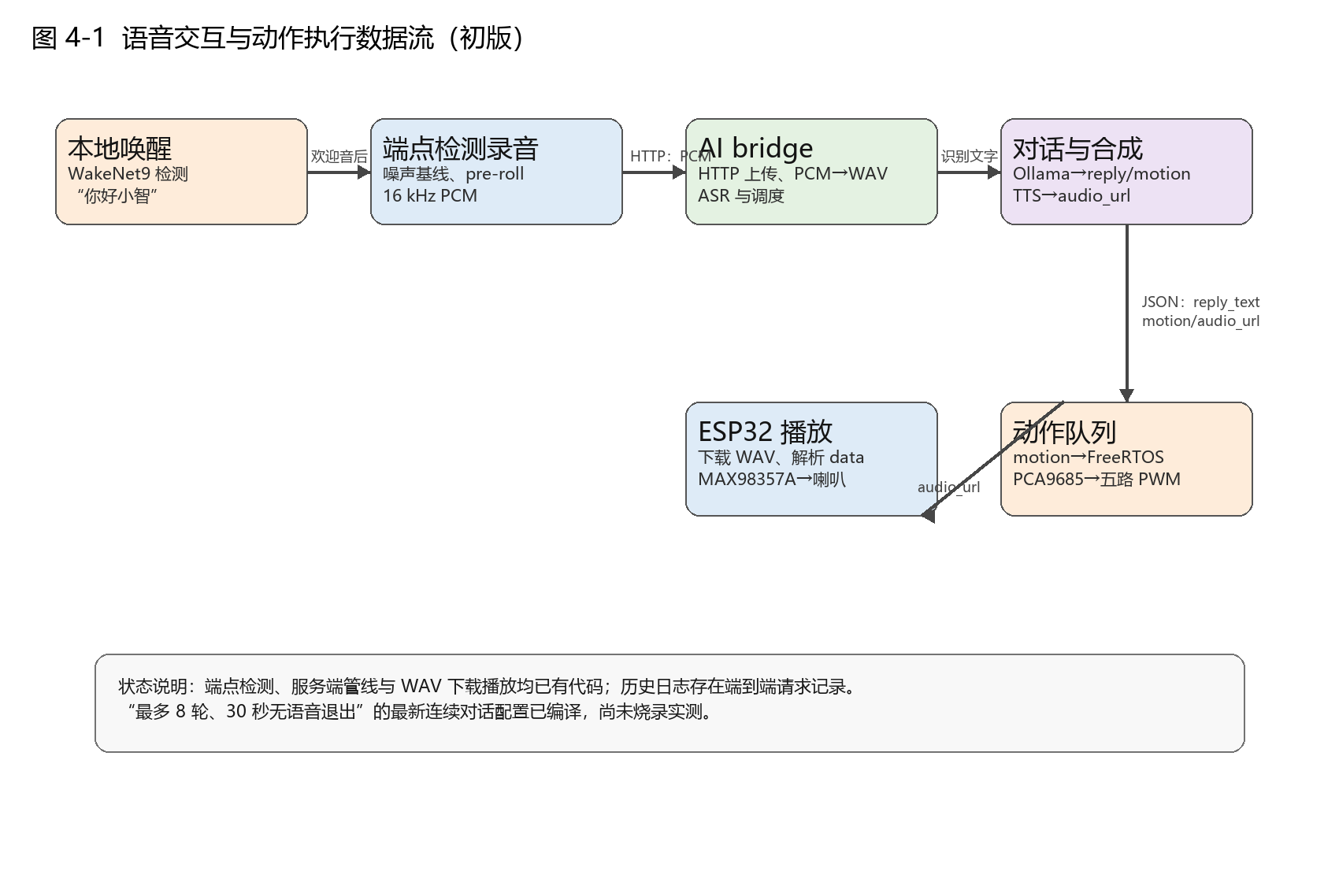
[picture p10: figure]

图4-1 语音交互与动作执行数据流

# 5 个性化设计

## 5.1 角色与回复风格

当前“糯糯”人设描述其为温暖、活泼、略带傲娇的毛绒小龙。提示词同时约束回复应使用简体中文、尽量短、适合语音播放，不进行医学诊断或承诺治疗效果；当出现明显危险、自伤或急症内容时，应鼓励用户寻求现实中的可信任人员或专业帮助。服务端当前提供 cute 和 encourage 两种情境风格，并保留最近四轮对话作为短期上下文。

## 5.2 可配置项目

可配置内容 | 配置位置 | 当前状态
角色名称与提示词 | server/prompts 与环境变量 | 已提供入口
LLM模型、超时与回复风格 | server_config.py / 环境变量 | 已提供入口
ASR模型、beam、best_of、热词 | server_config.py / 环境变量 | 已提供入口；热词默认关闭
TTS后端、参考音频与语言 | server_config.py / 环境变量 | 已提供入口
端点检测阈值与会话时间 | main/network_config.h | 已提供入口
舵机通道、角度范围与主页 | main/robot_config.h | 已提供入口，待机械校准
触摸输入 | main/robot_config.h | 代码预留，默认关闭

需要注意的是，配置入口不等于已经完成效果验证。例如，GPT-SoVITS 后端可由配置启用，但当前后台服务尚未运行该 API；触摸输入已有 GPIO 和动作映射，但未接硬件时默认关闭。论文中应将这些内容写为“可配置能力”或“待验证扩展”，而不能表述为成品功能。

# 6 开发过程、测试与讨论

## 6.1 录音和网络链路的迭代

项目早期采用固定5秒录音。该方式在短句场景中会引入额外静音和等待，而长句或停顿场景又可能出现截断。为此，固件保留固定时长函数作为回退，并新增端点检测函数，通过环境噪声基线、动态开始/停止阈值、80 ms 开口确认、300 ms pre-roll、最短录音时长和连续静音结束判定控制上传边界。该功能已经写入当前代码；需要在短句、长句、停顿和不开口场景下进一步采集串口日志和录音样本，才能形成端点完整率结论。

一次测试中，欢迎音播放后系统直接进入本地命令词模式，表面现象像是端点检测没有执行。排查后发现根因是 ai_bridge_ready 为 false 时触发了静默回退，且旧日志在 ready 判断前就打印了“准备录音”。后续修改为每次唤醒前检查 Wi-Fi 和 AI bridge 状态，并输出服务器地址和失败原因。该问题说明联网系统需要可观测性，不能仅依赖静默回退。

## 6.2 ASR、回复与TTS的迭代

ASR 从 tiny 调整为 small 后，解码参数修改为 beam_size=5、best_of=5，关闭跨片段文本条件，并增加繁体转简体。完整提示词和过强热词曾在短而含糊的录音中引发幻听，因此当前默认关闭，仅保留受控实验配置入口。非正式旧录音复查显示 small 模型对部分结果有改善，热启动单条识别约1.6～1.8秒；这只是开发观察，不能替代标准语料的统计实验。

回复生成方面，项目从规则话术逐步增加 Ollama 本地模型、角色提示词、短期上下文、情绪字段和动作字段。人设文件从业务代码拆出后，能够在不重写服务逻辑的情况下切换机器人形象。TTS 方面，Windows SAPI 被保留为稳定回退；GPT-SoVITS 适配了 api_v2 参数和 WAV 规范化，单独调试接口已成功生成可识别的16 kHz WAV，但当前整机端到端效果仍待验证。

## 6.3 动作与硬件问题的迭代

为适配四脚加尾巴，动作层从早期的少路、阻塞式控制调整为五通道配置和独立 FreeRTOS 动作任务。公开动作函数仅负责入队，执行任务负责插值和 PWM 写入。统一工程的五路版本已经编译，且 v2 固件曾成功烧录；实际复测中，GPIO8、GPIO9、GPIO10 未连接的触摸输入处于悬空状态，持续误触发动作并占满队列，导致正常串口舵机命令看似无效。修复方案是将 TOUCH_INPUTS_ENABLED 默认设为 false，并使关闭机器控制时清空待执行动作和请求复位。

修复后，用户实际测试了通道0的 servo fl 80 和 servo fl 100 指令，确认动作只入队一次且舵机运动符合预期。这证明了统一工程中 PCA9685 通道0、动作队列和悬空触摸修复的可用性，但不证明其余四通道、组合动作或五机大电流供电已通过。

## 6.4 当前测试结果与待补实验

测试项 | 当前结果 | 论文表述边界
单舵机台架 | 通道0正常运动，无尖叫 | 已实测；仅单机
五路动作代码 | 队列与插值编译通过 | 不可写成五机已稳定运行
历史AI端到端 | 存在 PCM 上传、200响应和WAV下载日志 | 证明历史链路通，不代表最新固件
ASR small | 四段旧录音的非正式改善观察 | 不可报告正式CER
GPT-SoVITS | 调试接口生成规范WAV | 当前整机联调待完成
连续对话v1 | 代码与编译完成 | 尚未烧录实测

后续实验应首先建立带人工标准文本的20～50条语料，在安静和普通室内噪声、20 cm和50 cm距离下记录唤醒成功率、误唤醒率、CER、整句正确率和端点完整率。响应速度应记录说话结束、上传完成、ASR完成、LLM完成、TTS完成、下载完成、播放开始和动作开始时间，并报告P50与P90。硬件部分应逐通道验证1至4，再从两机并发逐步扩展到五机，记录峰值电流、异常复位、温升、动作噪声和机械卡滞情况。

# 7 结论

本文完成了毛绒陪伴机器人语音与动作系统的初步设计与实现。系统采用 ESP32-S3 与电脑端 AI bridge 分工：前者负责本地音频采集、唤醒、网络通信、播放和动作执行，后者负责 faster-whisper 识别、Ollama 对话和 TTS 合成。硬件方案明确了 INMP441、MAX98357A、PCA9685 和五路舵机的通信关系，并提出了2S电池经5V稳压后使用星形分支、舵机独立大电流支路和所有模块共地的成品供电结构。

在软件实现方面，系统已具备端点检测录音、PCM 上传、结构化服务端返回、动态 WAV 下载播放、角色提示词加载和动作队列控制等能力。开发过程中针对固定时长录音、AI bridge 静默回退、ASR 幻听、角色一致性、TTS 格式、触摸悬空误触发和阻塞式动作等问题进行了多轮修改。当前已完成单舵机通道0的实际验证，并保留了历史语音端到端日志。

本项目仍处于原型迭代阶段。后续需要完成五路舵机与电源系统的实测、连续对话最新版固件的烧录、端点检测的系统化场景测试、标准 ASR 语料评估、GPT-SoVITS 整机联调及用户体验评价。只有在获得重复测试记录后，才能对识别准确率、延迟、稳定性和陪伴体验形成量化结论。

# 参考文献

[1] Espressif Systems. ESP32-S3 Series Datasheet[EB/OL]. https://www.espressif.com/sites/default/files/documentation/esp32-s3_datasheet_en.pdf.

[2] NXP Semiconductors. PCA9685 16-channel, 12-bit PWM Fm+ I2C-bus LED controller[EB/OL]. https://www.nxp.com/docs/en/data-sheet/PCA9685.pdf.

[3] TDK InvenSense. INMP441 High Accuracy Low Power Digital Output MEMS Microphone[EB/OL]. https://invensense.tdk.com/wp-content/uploads/2015/02/INMP441.pdf.

[4] Analog Devices. MAX98357A/MAX98357B PCM Input Class D Audio Power Amplifiers[EB/OL]. https://www.analog.com/media/en/technical-documentation/data-sheets/MAX98357A-MAX98357B.pdf.

[5] Radford A, Kim J W, Xu T, et al. Robust Speech Recognition via Large-Scale Weak Supervision[EB/OL]. arXiv:2212.04356, 2022.

[6] SYSTRAN. faster-whisper: Faster Whisper transcription with CTranslate2[EB/OL]. https://github.com/SYSTRAN/faster-whisper.

[7] Ollama. Ollama Documentation[EB/OL]. https://docs.ollama.com/.

[8] 毛绒治愈机器人PRP项目组. AI Bridge录音端点检测模块说明[Z]. 2026.

[9] 毛绒治愈机器人PRP项目组. 五舵机硬件集成与语音量化评估计划[Z]. 2026.

# 致谢

感谢指导教师在课题方向、系统设计和论文撰写方面给予的指导，感谢参与项目测试与讨论的同学提供意见，也感谢在硬件接线、语音录音和功能验证过程中给予帮助的人员。后续将继续完善实验记录，使本研究从可运行原型逐步发展为具有完整证据链的项目成果。

上海交通大学第 期PRP学生研究论文

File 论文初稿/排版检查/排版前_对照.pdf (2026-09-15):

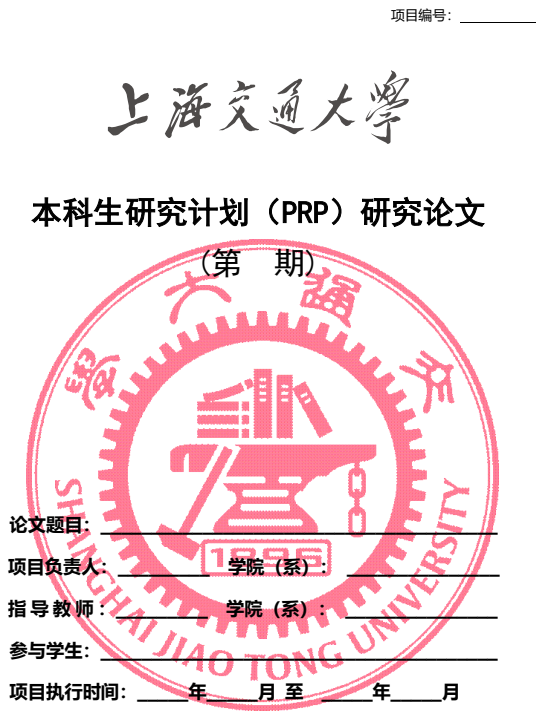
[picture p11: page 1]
项目编号：; 论文题目：_______________________________________; 项目负责人：_________ 学院（系）： _______________; 指导教师 ：_________ 学院（系）： _______________; 参与学生：_______________________________________; 项目执行时间：_____年_____月 至 _____年_____月

本科生研究计划（PRP）研究论文

PRP 研究论文撰写规范

ion control, companion robot

1 绪论

### 1.1 研究背景

毛绒玩具具有柔软、低压力和容易亲近的外观特点，适合承 载轻量化的陪伴交互。与只能播放固定音频的玩具相比，带有 语音理解、回复语音和动作反馈能力的毛绒机器人，能够在用 户表达疲惫、开心、焦虑或希望被陪伴时，给出相对自然的回 应，并通过身体动作增强交互感受。
本项目以“糯糯”毛绒小龙为机器人形象，目标不是构建医疗 诊断或心理治疗设备，而是实现一个可进行日常短对话、提供 温和陪伴和做出简单肢体反馈的原型系统。系统设计需要同时 处理嵌入式端本地唤醒与录音、无线音频传输、电脑端 AI 服 务调用、语音播放、五路舵机控制以及移动供电条件下的稳定 性。

### 1.2 研究目标与内容

本研究拟完成一个由嵌入式终端和电脑端 AI bridge 共同 组成的语音交互系统。ESP32-S3 负责本地唤醒词检测、麦克 风采集、网络通信、回复音频播放和动作执行；电脑端负责语 音识别、大语言模型回复和语音合成。这样的分工避免将较大 的 ASR、LLM 和 TTS 模型部署到资源有限的单片机中，同 时保留机器人本地的声音输入、声音输出和动作能力。
本文围绕硬件结构、语音数据流、动作调度、个性化配置和 测试方法展开。研究重点包括：设计五路舵机的供电和控制方

式；实现唤醒、端点检测录音、PCM 上传、ASR、LLM、TTS、 WAV 下载播放和动作执行链路；将角色提示词与业务代码解

耦；建立对识别准确率、响应耗时和动作稳定性的测试方案。

### 1.3 研究范围与证据边界

本文重点讨论原型系统的软硬件设计、实现过程和测试方
法。当前代码中已经配置了前左、前右、后左、后右和尾巴五 个舵机通道，并完成了动作队列与同步插值逻辑；但实际硬件

验证目前仅覆盖 PCA9685 通道 0 的一只 SG90 舵机。因此， 文中将严格区分“五路控制代码已实现”和“五舵机整机已稳定运 行”。

当前服务端已配置 faster-whisper small 模型、Ollama

qwen2.5:3b 模型和 Windows SAPI TTS；GPT-SoVITS 已完 成单独接口联调，但尚未形成其在 ESP32 整机上的稳定播放 证据。连续对话的最新“30 秒无语音退出、最多 8 轮”固件已通 过编译，尚未烧录实测。后续章节中的状态描述均以“设计计划、 已写入代码、已编译、已烧录、已实测、已有量化数据”作为判 断依据。

2 系统总体方案

### 2.1 四层架构

系统按职责分为四层。用户交互层负责用户说话、唤醒机器 人、收听回复和观察动作；设备感知与执行层负责音频采集、 播放和舵机输出；通信与业务调度层负责 Wi-Fi、HTTP、

PCM/WAV 处理和 JSON 结果汇总；AI 能力层负责语音识 别、对话生成、角色约束、语音合成和动作意图生成。供电系 统不属于其中单独一层，而是支撑设备层全部模块的基础设施。

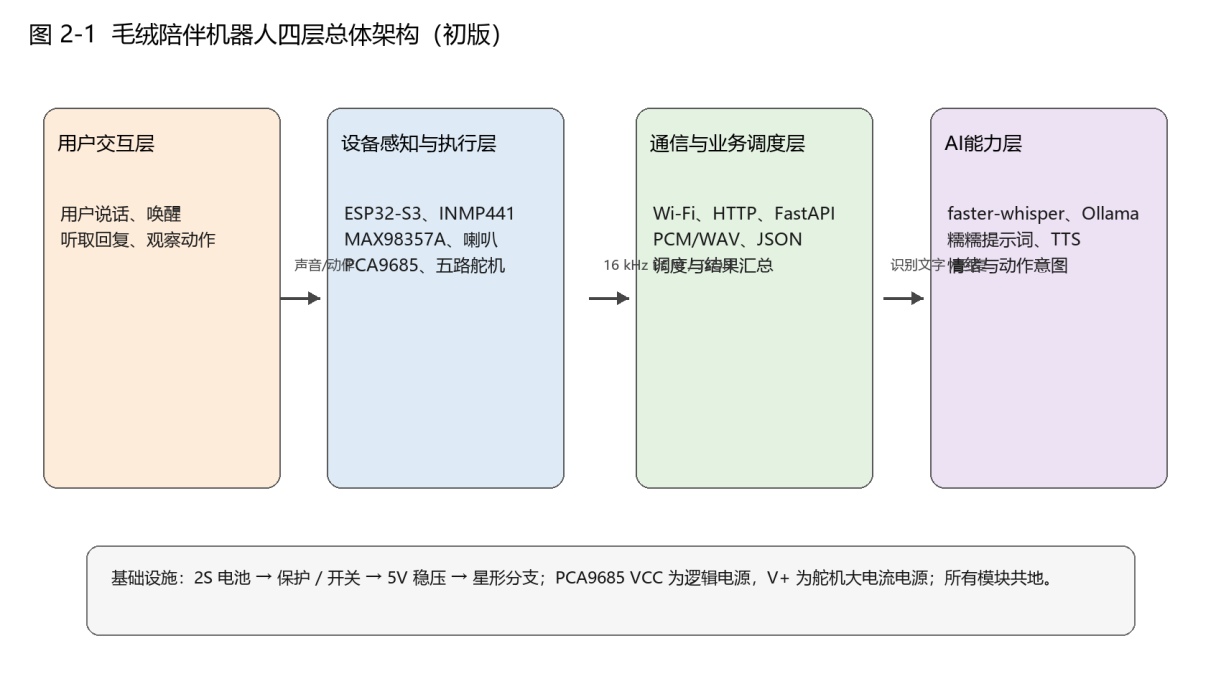
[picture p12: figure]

图 2-1 毛绒陪伴机器人四层总体架构

### 2.2 终端与服务端分工

ESP32-S3 侧的任务强调低时延和与物理设备直接相连，包

括 WakeNet 本地唤醒、INMP441 音频读取、端点检测、HTTP 上传、WAV 音频播放以及 PCA9685 动作控制。电脑端服务

采用 FastAPI 组织 AI bridge，接收原始 PCM 后转换为

WAV，依次调用 ASR、对话服务和 TTS 服务，并以 JSON 返 回识别文字、回复、动作、音频地址和耗时。该方式使服务端

模型可以独立替换，ESP32 不需要因更换 ASR、LLM 或 TTS 后端而重新设计协议。

### 2.3 已实现状态

子系统 | 当前实现 | 证据状态
本地唤醒 | WakeNet9 与“你好小智”模型 | 已写入代码；历史使用
录音 | 端点检测、噪声基线、pre-roll、静音结束 | 已写入代码；待系统量化
AI bridge | PCM 上传、ASR、Ollama、TTS、JSON 返 回 | 已写入代码；历史端到端日志
连续对话 | 最多 8 轮、30 秒无语音退出 | 已编译，未烧录实测
动作控制 | 五路配置、队列、同步插值 | 已编译；通道 0 单机实测

五舵机整机 | 并发、负载和温升 | 待连接与测试

3 硬件系统设计

### 3.1 硬件组成与职责

硬件部分以 ESP32-S3 为核心。INMP441 是数字 MEMS

麦克风，使用 I2S 输出音频数据；MAX98357A 是 I2S 数字 功放，将 ESP32 输出的数字音频转换为可驱动喇叭的信号；

PCA9685 是 16 通道 PWM 驱动器，通过 I2C 接收控制命 令后输出舵机脉冲。原型方案使用 PCA9685 的前五个通道分 别连接四个脚部舵机和一个尾巴舵机，便于后续扩展和独立校 准。

模块 | 作用 | 当前状态
ESP32-S3 | 本地语音、Wi-Fi、播放和动作调度 | 当前统一工程主控
INMP441 | 采集用户语音并输出 I2S 数据 | GPIO 已由代码固定
MAX98357A+喇叭 | 播放欢迎音和服务端回复音频 | 代码支持 WAV 下载与播 放
PCA9685 | 输出五路舵机 PWM | 通道 0 已实际验证
SG90 或后续选型舵机 | 脚部和尾巴姿态动作 | 其余四路待验证
2S 电池、保护、降压 | 移动供电与电压转换 | 成品方案待整机验证

### 3.2 GPIO 与通信连接

当前固件将 INMP441 的 WS、SCK 和 SD 分别固定为

GPIO4、GPIO5 和 GPIO6；MAX98357A 的 BCLK、LRC 和

DIN 分别使用 GPIO15、GPIO16 和 GPIO7。PCA9685 通

过 I2C 与 ESP32-S3 通信，GPIO1 为 SDA，GPIO2 为

SCL，I2C 时钟设为 100 kHz。该分配以当前代码为依据，不 能沿用早期单舵机直连 GPIO18 的示例。GPIO18 对应的旧

ServoController 文 件 仍 保 留 在 工 程 中 ， 但 不 属 于 当 前

PCA9685 五舵机方案。

ESP32-S3 引脚 | 连接模块引脚 | 通信/用途
GPIO4 | INMP441 WS/LRCLK | I2S 输入字选择
GPIO5 | INMP441 SCK/BCLK | I2S 输入位时钟
GPIO6 | INMP441 SD | I2S 输入数据
GPIO7 | MAX98357A DIN | I2S 输出数据
GPIO15 | MAX98357A BCLK | I2S 输出位时钟
GPIO16 | MAX98357A LRC | I2S 输出左右声道时钟
GPIO1 | PCA9685 SDA | I2C 数据
GPIO2 | PCA9685 SCL | I2C 时钟

### 3.3 五路舵机与安全限位

PCA9685 通道 0 至 4 依次分配给前左、前右、后左、后右 和尾巴。当前脚部保守角度范围为 70°至 110°，尾巴为 60°至 120°，主页均为 90°。这些数值来自空载台架安全限制，尚未 根据实际毛绒骨架、舵机安装方向和机械干涉完成标定。软件 对于超出范围的串口命令直接拒绝，以减少初期测试中撞限位 和卡滞的风险。

PCA9685 通道 | 肢体 | 当前范围 | 状态
0 | 前左 | 70°～110° | 已单机实测
1 | 前右 | 70°～110° | 待测
2 | 后左 | 70°～110° | 待测
3 | 后右 | 70°～110° | 待测
4 | 尾巴 | 60°～120° | 待测

### 3.4 供电与共地设计

PCA9685 板上的 VCC 和 V+ 必须区分。VCC 用于驱动 芯片的逻辑供电，应接 ESP32 的 3.3V；V+ 是舵机供电排， 应连接外部稳压 5V。舵机的信号电压需要以 ESP32 为参考，

因此 ESP32、PCA9685 和外部 5V 电源必须共地。共地不是 让舵机从 ESP32 取电，而是建立统一的信号参考电位。 五个舵机启动、换向或受阻时可能出现较大的瞬时电流。若

让它们通过 ESP32 开发板的 5V 或 3.3V 引脚供电，可能造成 板载稳压器过载、压降或复位，也会把电机噪声带入音频链路。 因此，成品设计采用 2S 电池经过保护、保险丝和总开关后进入 5V 大电流稳压模块，再以星形分支分别供给 PCA9685 V+、 ESP32 的 5V/VIN 和音频模块。舵机支路入口应配置大容量低 ESR 电容，电源线需采用能承载电流的线材；普通杜邦线和面 包板不适合承载整机舵机电流。

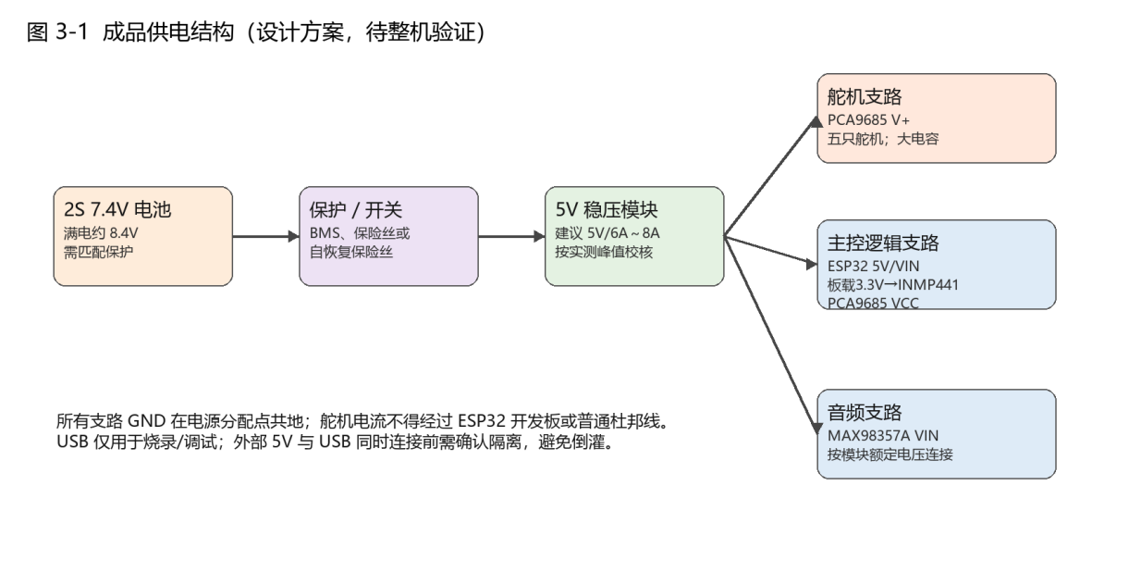
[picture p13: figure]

图 3-1 成品供电结构（设计方案，待整机验证）

4 软件系统与交互流程

### 4.1 ESP32 语音状态机

设备上电后初始化音频输入输出、唤醒模型、命令词模型、 Wi-Fi 和动作模块，并进入等待唤醒状态。检测到“你好小智” 后，系统播放本地欢迎音。若 AI bridge 已连接，则进入端点 检测录音；若网络或服务不可用，则保留本地命令词模式作为 回退。该回退机制最初只表现为静默切换，容易被误认为端点

检测故障，后续已增加 Wi-Fi 状态、服务器地址和 AI bridge

ready 状态日志。
端点检测先采集环境噪声估计 noise_floor，然后在等待开口 阶段维护短时 pre-roll 环形缓冲。当 RMS 连续超过动态开始 阈值达到确认时间后，系统把 pre-roll 写入正式录音并进入录 音状态；在达到最短录音时长后，连续静音达到设定时间则结 束；达到最长时长时也会强制结束。录音结果是 16 kHz、16 bit、 单声道 PCM。

### 4.2 AI bridge 调度

ESP32 使用 HTTP POST 上传 PCM，并在请求头中传递 采样率和音频格式。FastAPI 服务保存原始 PCM，同时进行音

量归一化后写入 WAV。服务端顺序调用 faster-whisper、对话

服务和 TTS 服务，最后返回 recognized_text、reply_text、

reply_emotion、motion、audio_url、timings_ms 等字段。ASR、 LLM 和 TTS 存在数据依赖，因此当前链路以顺序调用为主。

当前 ASR 使用 faster-whisper small 、 CPU int8 、

beam_size=5、best_of=5，并关闭跨片段文本条件；识别结果 使用 OpenCC 转换为简体。初步的四段旧录音复查显示 small 模型在部分错句上优于原 tiny 模型，但旧样本没有完整人工标 准 文 本 ， 不 能 据 此 报 告 正 式 字 错 误 率 。 服 务 端 提 供

benchmark_asr.py 脚本，后续可对带参考文本的 20～50 条语 料计算 CER、整句正确率和耗时。

### 4.3 回复生成、TTS 与动作意图

对话服务默认调用 Ollama 中的 qwen2.5:3b 模型。角色设 定存放在独立的 nuonuo_v1.txt 文件中，业务代码通过配置读

取，使机器人名称、表达方式和安全边界能够在不修改对话逻

辑的情况下切换。模型被要求返回 reply_text、style、emotion 和 motion 字段，服务端再根据用户输入校正情绪与动作，避 免负面情绪被误配为 happy。若 Ollama 不可用或返回解析失 败，服务端使用规则回复兜底并标记状态。

TTS 服务提供 Windows SAPI 和 GPT-SoVITS 两个后

端。所有输出在服务端统一为 ESP32 可播放的16 kHz、16 bit、

单声道 WAV。当前后台 AI bridge 默认采用 Windows SAPI； GPT-SoVITS 已在调试接口生成过规范 WAV，但未完成当前 整机的持续联调。ESP32 下载完整 WAV 后解析 data 区块

并通过 I2S 送往 MAX98357A 播放。

### 4.4 动作队列与同步插值

服务端 motion 字段支持 happy、shy、comfort、curious 和 none。ESP32 在机器控制开关开启时把相应意图投递到长度 为 8 的 FreeRTOS 队列。动作任务从队列中取出命令，按照 目标姿态和当前姿态之间的最大角度差确定插值步数，再同步 更新五个通道，避免网络、录音或播放任务直接执行长时间阻

塞动作。当前 comfort 和 curious 在执行端共用 curious 动 作，属于第一版动作映射，后续应结合整机外观和用户体验继 续细化。

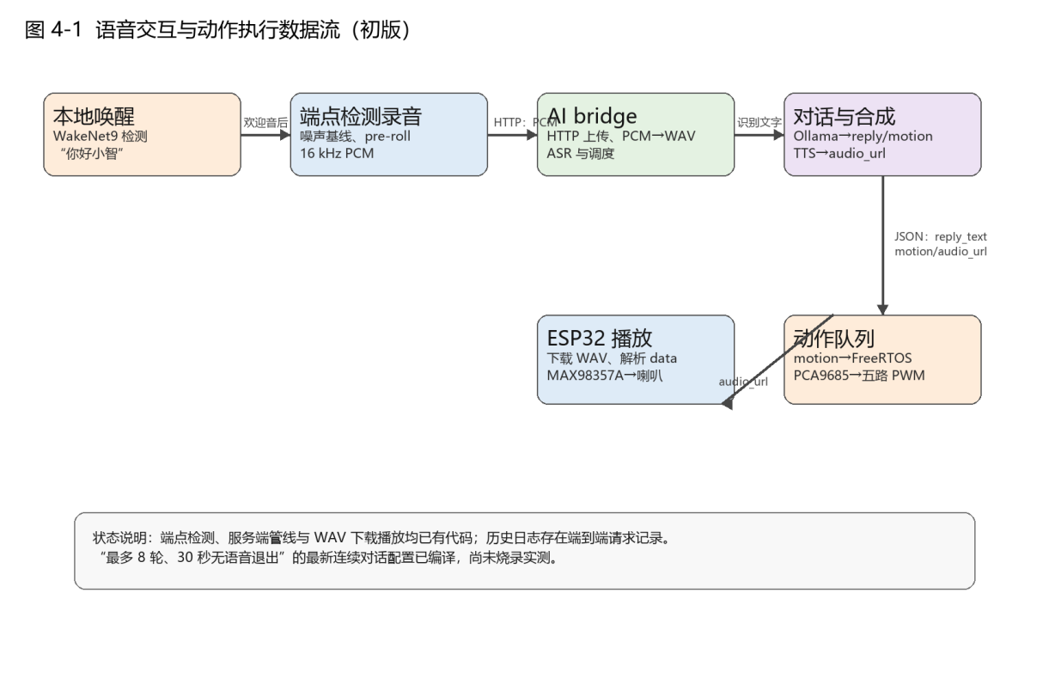
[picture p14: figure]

图 4-1 语音交互与动作执行数据流

5 个性化设计

### 5.1 角色与回复风格

当前“糯糯”人设描述其为温暖、活泼、略带傲娇的毛绒小龙。 提示词同时约束回复应使用简体中文、尽量短、适合语音播放， 不进行医学诊断或承诺治疗效果；当出现明显危险、自伤或急 症内容时，应鼓励用户寻求现实中的可信任人员或专业帮助。 服务端当前提供 cute 和 encourage 两种情境风格，并保留最 近四轮对话作为短期上下文。

### 5.2 可配置项目

可配置内容 | 配置位置 | 当前状态
角色名称与提示词 | server/prompts 与环境变量 | 已提供入口
LLM 模型、超时与回复风 格 | server_config.py / 环境变量 | 已提供入口
ASR 模型、 beam 、 best_of、热词 | server_config.py / 环境变量 | 已提供入口；热词默认关闭

TTS 后端、参考音频与语 言 | server_config.py / 环境变量 | 已提供入口
端点检测阈值与会话时间 | main/network_config.h | 已提供入口
舵机通道、角度范围与主 页 | main/robot_config.h | 已提供入口，待机械校准
触摸输入 | main/robot_config.h | 代码预留，默认关闭

需要注意的是，配置入口不等于已经完成效果验证。例如， GPT-SoVITS 后端可由配置启用，但当前后台服务尚未运行该 API；触摸输入已有 GPIO 和动作映射，但未接硬件时默认关 闭。论文中应将这些内容写为“可配置能力”或“待验证扩展”，而 不能表述为成品功能。

6 开发过程、测试与讨论

### 6.1 录音和网络链路的迭代

项目早期采用固定 5 秒录音。该方式在短句场景中会引入额 外静音和等待，而长句或停顿场景又可能出现截断。为此，固 件保留固定时长函数作为回退，并新增端点检测函数，通过环 境噪声基线、动态开始/停止阈值、80 ms 开口确认、300 ms pre-roll、最短录音时长和连续静音结束判定控制上传边界。该 功能已经写入当前代码；需要在短句、长句、停顿和不开口场 景下进一步采集串口日志和录音样本，才能形成端点完整率结 论。
一次测试中，欢迎音播放后系统直接进入本地命令词模式， 表 面 现 象 像 是 端 点 检 测 没 有 执 行 。 排 查 后 发 现 根 因 是

ai_bridge_ready 为 false 时触发了静默回退，且旧日志在 ready 判断前就打印了“准备录音”。后续修改为每次唤醒前检查

Wi-Fi 和 AI bridge 状态，并输出服务器地址和失败原因。该

问题说明联网系统需要可观测性，不能仅依赖静默回退。

### 6.2 ASR、回复与 TTS 的迭代

ASR 从 tiny 调整为 small 后 ， 解 码 参 数 修 改 为

beam_size=5、best_of=5，关闭跨片段文本条件，并增加繁体 转简体。完整提示词和过强热词曾在短而含糊的录音中引发幻 听，因此当前默认关闭，仅保留受控实验配置入口。非正式旧 录音复查显示 small 模型对部分结果有改善，热启动单条识别 约 1.6～1.8 秒；这只是开发观察，不能替代标准语料的统计实 验。
回复生成方面，项目从规则话术逐步增加 Ollama 本地模 型、角色提示词、短期上下文、情绪字段和动作字段。人设文 件从业务代码拆出后，能够在不重写服务逻辑的情况下切换机

器人形象。TTS 方面，Windows SAPI 被保留为稳定回退；

GPT-SoVITS 适配了 api_v2 参数和 WAV 规范化，单独调试 接口已成功生成可识别的 16 kHz WAV，但当前整机端到端效 果仍待验证。

### 6.3 动作与硬件问题的迭代

为适配四脚加尾巴，动作层从早期的少路、阻塞式控制调整 为五通道配置和独立 FreeRTOS 动作任务。公开动作函数仅 负责入队，执行任务负责插值和 PWM 写入。统一工程的五路 版本已经编译，且 v2 固件曾成功烧录；实际复测中，GPIO8、 GPIO9、GPIO10 未连接的触摸输入处于悬空状态，持续误触 发动作并占满队列，导致正常串口舵机命令看似无效。修复方

案是将 TOUCH_INPUTS_ENABLED 默认设为 false，并使关

闭机器控制时清空待执行动作和请求复位。

修复后，用户实际测试了通道 0 的 servo fl 80 和 servo fl 100 指令，确认动作只入队一次且舵机运动符合预期。这证明 了统一工程中 PCA9685 通道 0、动作队列和悬空触摸修复的 可用性，但不证明其余四通道、组合动作或五机大电流供电已 通过。

### 6.4 当前测试结果与待补实验

测试项 | 当前结果 | 论文表述边界
单舵机台架 | 通道 0 正常运动，无尖叫 | 已实测；仅单机
五路动作代码 | 队列与插值编译通过 | 不可写成五机已稳定运行
历史 AI 端到端 | 存在 PCM 上传、200 响应和 WAV 下载 日志 | 证明历史链路通，不代表最新固件
ASR small | 四段旧录音的非正式改善观察 | 不可报告正式 CER
GPT-SoVITS | 调试接口生成规范 WAV | 当前整机联调待完成
连续对话 v1 | 代码与编译完成 | 尚未烧录实测

后续实验应首先建立带人工标准文本的 20～50 条语料，在 安静和普通室内噪声、20 cm 和 50 cm 距离下记录唤醒成功率、 误唤醒率、CER、整句正确率和端点完整率。响应速度应记录 说话结束、上传完成、ASR 完成、LLM 完成、TTS 完成、下载 完成、播放开始和动作开始时间，并报告 P50 与 P90。硬件部 分应逐通道验证 1 至 4，再从两机并发逐步扩展到五机，记录 峰值电流、异常复位、温升、动作噪声和机械卡滞情况。

7 结论
本文完成了毛绒陪伴机器人语音与动作系统的初步设计与

实现。系统采用 ESP32-S3 与电脑端 AI bridge 分工：前者负 责本地音频采集、唤醒、网络通信、播放和动作执行，后者负

责 faster-whisper 识别、Ollama 对话和 TTS 合成。硬件方

案明确了 INMP441、MAX98357A、PCA9685 和五路舵机的 通信关系，并提出了 2S 电池经 5V 稳压后使用星形分支、舵机 独立大电流支路和所有模块共地的成品供电结构。
在软件实现方面，系统已具备端点检测录音、PCM 上传、 结构化服务端返回、动态 WAV 下载播放、角色提示词加载和 动作队列控制等能力。开发过程中针对固定时长录音、AI bridge 静默回退、ASR 幻听、角色一致性、TTS 格式、触摸悬空误 触发和阻塞式动作等问题进行了多轮修改。当前已完成单舵机 通道 0 的实际验证，并保留了历史语音端到端日志。
本项目仍处于原型迭代阶段。后续需要完成五路舵机与电源 系统的实测、连续对话最新版固件的烧录、端点检测的系统化

场景测试、标准 ASR 语料评估、GPT-SoVITS 整机联调及用 户体验评价。只有在获得重复测试记录后，才能对识别准确率、 延迟、稳定性和陪伴体验形成量化结论。

参考文献
[1] Espressif Systems. ESP32-S3 Series Datasheet[EB/OL]. https://www.espressif.com/sites/default/files/documentation/esp32-s3_datasheet_en.pdf.
[2] NXP Semiconductors. PCA9685 16-channel, 12-bit PWM
Fm+ | | I2C-bus | LED | controller[EB/OL].
https://www.nxp.com/docs/en/data-sheet/PCA9685.pdf.
[3] TDK InvenSense. INMP441 High Accuracy Low Power
Digital | | Output | MEMS | Microphone[EB/OL].
https://invensense.tdk.com/wp-content/uploads/2015/02/INM P441.pdf.
[4] Analog Devices. MAX98357A/MAX98357B PCM Input
Class | D | Audio | Power | Amplifiers[EB/OL].
https://www.analog.com/media/en/technical-documentation/data-sheets/MAX98357A-MAX98357B.pdf.

[5] Radford A, Kim J W, Xu T, et al. Robust Speech Recognition via Large-Scale Weak Supervision[EB/OL]. arXiv:2212.04356, 2022.
[6] SYSTRAN. faster-whisper: Faster Whisper transcription
with | | | CTranslate2[EB/OL].
https://github.com/SYSTRAN/faster-whisper.
[7] | Ollama. | Ollama | Documentation[EB/OL].
https://docs.ollama.com/.
[8] 毛绒治愈机器人 PRP 项目组. AI Bridge 录音端点检测模块

说明[Z]. 2026.
[9] 毛绒治愈机器人 PRP 项目组. 五舵机硬件集成与语音量化

评估计划[Z]. 2026.

致谢

感谢指导教师在课题方向、系统设计和论文撰写方面给予的指导，感谢参与项目测 试与讨论的同学提供意见，也感谢在硬件接线、语音录音和功能验证过程中给予帮 助的人员。后续将继续完善实验记录，使本研究从可运行原型逐步发展为具有完整 证据链的项目成果。

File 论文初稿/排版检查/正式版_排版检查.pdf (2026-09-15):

项目编号：; 论文题目：_______________________________________; 项目负责人：_________ 学院（系）： _______________; 指导教师 ：_________ 学院（系）： _______________; 参与学生：_______________________________________; 项目执行时间：_____年_____月 至 _____年_____月

本科生研究计划（PRP）研究论文

上海交通大学第 期 PRP 学生研究论文

摘要
面向日常陪伴场景中用户对自然语音交互、情绪回应和具身动作反馈的需求，本文设计并实现 了一套毛绒陪伴机器人语音与动作系统。系统以 ESP32-S3 为本地感知与执行终端，连接 INMP441 数字麦克风、MAX98357A 数字功放、扬声器、PCA9685 舵机驱动板及四个脚部舵机和一个尾巴舵 机；电脑端 AI bridge 负责语音识别、对话生成和语音合成等计算量较大的任务。用户说出唤醒词 后，设备进行端点检测录音，并通过 Wi-Fi 将 16 kHz PCM 语音上传至服务端；服务端依次完成 faster-whisper 语音识别、基于“糯糯”角色提示词的 Ollama 对话生成及 TTS 合成，返回回复文本、 动作意图、耗时和音频地址。ESP32 下载并播放 WAV 音频，同时将动作意图投入 FreeRTOS 动 作队列，由 PCA9685 输出五路 PWM 信号。本文还记录了录音端点检测、ASR 参数、角色提示 词、TTS 回退、触摸悬空误触发和舵机供电等调试过程。当前已完成语音链路与单舵机通道 0 的实 际验证；五舵机并发、连续对话新版固件和量化实验仍待进一步测试。 关键词：毛绒机器人，语音交互，ESP32-S3，动作控制，陪伴机器人

### ABSTRACT

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

### 1 绪论

### 1.1 研究背景

毛绒玩具具有柔软、低压力和容易亲近的外观特点，适合承载轻量化的陪伴交互。与只能播放 固定音频的玩具相比，带有语音理解、回复语音和动作反馈能力的毛绒机器人，能够在用户表达疲 惫、开心、焦虑或希望被陪伴时，给出相对自然的回应，并通过身体动作增强交互感受。 本项目以“糯糯”毛绒小龙为机器人形象，目标不是构建医疗诊断或心理治疗设备，而是实现一 个可进行日常短对话、提供温和陪伴和做出简单肢体反馈的原型系统。系统设计需要同时处理嵌入 式端本地唤醒与录音、无线音频传输、电脑端 AI 服务调用、语音播放、五路舵机控制以及移动供 电条件下的稳定性。

### 1.2 研究目标与内容

本研究拟完成一个由嵌入式终端和电脑端 AI bridge 共同组成的语音交互系统。ESP32-S3 负责 本地唤醒词检测、麦克风采集、网络通信、回复音频播放和动作执行；电脑端负责语音识别、大语 言模型回复和语音合成。这样的分工避免将较大的 ASR、LLM 和 TTS 模型部署到资源有限的单 片机中，同时保留机器人本地的声音输入、声音输出和动作能力。 本文围绕硬件结构、语音数据流、动作调度、个性化配置和测试方法展开。研究重点包括：设 计五路舵机的供电和控制方式；实现唤醒、端点检测录音、PCM 上传、ASR、LLM、TTS、WAV 下 载播放和动作执行链路；将角色提示词与业务代码解耦；建立对识别准确率、响应耗时和动作稳定 性的测试方案。

### 1.3 研究范围与证据边界

本文重点讨论原型系统的软硬件设计、实现过程和测试方法。当前代码中已经配置了前左、前 右、后左、后右和尾巴五个舵机通道，并完成了动作队列与同步插值逻辑；但实际硬件验证目前仅 覆盖 PCA9685 通道 0 的一只 SG90 舵机。因此，文中将严格区分“五路控制代码已实现”和“五舵机 整机已稳定运行”。
当前服务端已配置 faster-whisper small 模型、Ollama qwen2.5:3b 模型和 Windows SAPI TTS； GPT-SoVITS 已完成单独接口联调，但尚未形成其在 ESP32 整机上的稳定播放证据。连续对话的 最新“30 秒无语音退出、最多 8 轮”固件已通过编译，尚未烧录实测。后续章节中的状态描述均以“设 计计划、已写入代码、已编译、已烧录、已实测、已有量化数据”作为判断依据。

### 2 系统总体方案

### 2.1 四层架构

系统按职责分为四层。用户交互层负责用户说话、唤醒机器人、收听回复和观察动作；设备感 知与执行层负责音频采集、播放和舵机输出；通信与业务调度层负责 Wi-Fi、HTTP、PCM/WAV 处 理和 JSON 结果汇总；AI 能力层负责语音识别、对话生成、角色约束、语音合成和动作意图生成。 供电系统不属于其中单独一层，而是支撑设备层全部模块的基础设施。


图 2-1 毛绒陪伴机器人四层总体架构

### 2.2 终端与服务端分工

ESP32-S3 侧的任务强调低时延和与物理设备直接相连，包括 WakeNet 本地唤醒、INMP441 音 频读取、端点检测、HTTP 上传、WAV 音频播放以及 PCA9685 动作控制。电脑端服务采用 FastAPI 组织 AI bridge，接收原始 PCM 后转换为 WAV，依次调用 ASR、对话服务和 TTS 服务，并以 JSON 返回识别文字、回复、动作、音频地址和耗时。该方式使服务端模型可以独立替换，ESP32 不 需要因更换 ASR、LLM 或 TTS 后端而重新设计协议。

### 2.3 已实现状态

子系统 | 当前实现 | 证据状态
本地唤醒 | WakeNet9 与“你好小智”模型 | 已写入代码；历史使用
录音 | 端点检测、噪声基线、pre-roll、静音结束 | 已写入代码；待系统量化
AI bridge | PCM 上传、ASR、Ollama、TTS、JSON 返回 | 已写入代码；历史端到端日 志
连续对话 | 最多 8 轮、30 秒无语音退出 | 已编译，未烧录实测
动作控制 | 五路配置、队列、同步插值 | 已编译；通道 0 单机实测
五舵机整机 | 并发、负载和温升 | 待连接与测试

### 3 硬件系统设计

### 3.1 硬件组成与职责

硬件部分以 ESP32-S3 为核心。INMP441 是数字 MEMS 麦克风，使用 I2S 输出音频数据； MAX98357A 是 I2S 数字功放，将 ESP32 输出的数字音频转换为可驱动喇叭的信号；PCA9685 是 16 通道 PWM 驱动器，通过 I2C 接收控制命令后输出舵机脉冲。原型方案使用 PCA9685 的前五 个通道分别连接四个脚部舵机和一个尾巴舵机，便于后续扩展和独立校准。
模块 | 作用 | 当前状态
ESP32-S3 | 本地语音、Wi-Fi、播放和动作调度 | 当前统一工程主控
INMP441 | 采集用户语音并输出 I2S 数据 | GPIO 已由代码固定
MAX98357A+喇叭 | 播放欢迎音和服务端回复音频 | 代码支持 WAV 下载 与播放
PCA9685 | 输出五路舵机 PWM | 通道 0 已实际验证

模块 | 作用 | 当前状态
SG90 或后续选型 舵机 | 脚部和尾巴姿态动作 | 其余四路待验证
2S 电池、保护、降 压 | 移动供电与电压转换 | 成品方案待整机验证

### 3.2 GPIO 与通信连接

当前固件将 INMP441 的 WS、SCK 和 SD 分别固定为 GPIO4、GPIO5 和 GPIO6； MAX98357A 的 BCLK、LRC 和 DIN 分别使用 GPIO15、GPIO16 和 GPIO7。PCA9685 通过 I2C 与 ESP32-S3 通信，GPIO1 为 SDA，GPIO2 为 SCL，I2C 时钟设为 100 kHz。该分配以当前代码 为依据，不能沿用早期单舵机直连 GPIO18 的示例。GPIO18 对应的旧 ServoController 文件仍保留 在工程中，但不属于当前 PCA9685 五舵机方案。
ESP32-S3 引脚 | 连接模块引脚 | 通信/用途
GPIO4 | INMP441 WS/LRCLK | I2S 输入字选择
GPIO5 | INMP441 SCK/BCLK | I2S 输入位时钟
GPIO6 | INMP441 SD | I2S 输入数据
GPIO7 | MAX98357A DIN | I2S 输出数据
GPIO15 | MAX98357A BCLK | I2S 输出位时钟
GPIO16 | MAX98357A LRC | I2S 输出左右声道时钟
GPIO1 | PCA9685 SDA | I2C 数据
GPIO2 | PCA9685 SCL | I2C 时钟

### 3.3 五路舵机与安全限位

PCA9685 通道 0 至 4 依次分配给前左、前右、后左、后右和尾巴。当前脚部保守角度范围为 70° 至 110°，尾巴为 60°至 120°，主页均为 90°。这些数值来自空载台架安全限制，尚未根据实际毛绒骨 架、舵机安装方向和机械干涉完成标定。软件对于超出范围的串口命令直接拒绝，以减少初期测试 中撞限位和卡滞的风险。
PCA9685 通道 | 肢体 | 当前范围 | 状态
0 | 前左 | 70°～110° | 已单机实测
1 | 前右 | 70°～110° | 待测
2 | 后左 | 70°～110° | 待测
3 | 后右 | 70°～110° | 待测
4 | 尾巴 | 60°～120° | 待测

### 3.4 供电与共地设计

PCA9685 板上的 VCC 和 V+ 必须区分。VCC 用于驱动芯片的逻辑供电，应接 ESP32 的 3.3V；V+ 是舵机供电排，应连接外部稳压 5V。舵机的信号电压需要以 ESP32 为参考，因此 ESP32、 PCA9685 和外部 5V 电源必须共地。共地不是让舵机从 ESP32 取电，而是建立统一的信号参考电 位。
五个舵机启动、换向或受阻时可能出现较大的瞬时电流。若让它们通过 ESP32 开发板的 5V 或 3.3V 引脚供电，可能造成板载稳压器过载、压降或复位，也会把电机噪声带入音频链路。因此，成 品设计采用 2S 电池经过保护、保险丝和总开关后进入 5V 大电流稳压模块，再以星形分支分别供给 PCA9685 V+、ESP32 的 5V/VIN 和音频模块。舵机支路入口应配置大容量低 ESR 电容，电源线需 采用能承载电流的线材；普通杜邦线和面包板不适合承载整机舵机电流。


图 3-1 成品供电结构（设计方案，待整机验证）

### 4 软件系统与交互流程

### 4.1 ESP32 语音状态机

设备上电后初始化音频输入输出、唤醒模型、命令词模型、Wi-Fi 和动作模块，并进入等待唤 醒状态。检测到“你好小智”后，系统播放本地欢迎音。若 AI bridge 已连接，则进入端点检测录音； 若网络或服务不可用，则保留本地命令词模式作为回退。该回退机制最初只表现为静默切换，容易 被误认为端点检测故障，后续已增加 Wi-Fi 状态、服务器地址和 AI bridge ready 状态日志。 端点检测先采集环境噪声估计 noise_floor，然后在等待开口阶段维护短时 pre-roll 环形缓冲。 当 RMS 连续超过动态开始阈值达到确认时间后，系统把 pre-roll 写入正式录音并进入录音状态； 在达到最短录音时长后，连续静音达到设定时间则结束；达到最长时长时也会强制结束。录音结果 是 16 kHz、16 bit、单声道 PCM。

### 4.2 AI bridge 调度

ESP32 使用 HTTP POST 上传 PCM，并在请求头中传递采样率和音频格式。FastAPI 服务保 存原始 PCM，同时进行音量归一化后写入 WAV。服务端顺序调用 faster-whisper、对话服务和 TTS 服务，最后返回 recognized_text、reply_text、reply_emotion、motion、audio_url、timings_ms 等字段。 ASR、LLM 和 TTS 存在数据依赖，因此当前链路以顺序调用为主。
当前 ASR 使用 faster-whisper small、CPU int8、beam_size=5、best_of=5，并关闭跨片段文本条 件；识别结果使用 OpenCC 转换为简体。初步的四段旧录音复查显示 small 模型在部分错句上优于 原 tiny 模型，但旧样本没有完整人工标准文本，不能据此报告正式字错误率。服务端提供 benchmark_asr.py 脚本，后续可对带参考文本的 20～50 条语料计算 CER、整句正确率和耗时。

### 4.3 回复生成、TTS 与动作意图

对话服务默认调用 Ollama 中的 qwen2.5:3b 模型。角色设定存放在独立的 nuonuo_v1.txt 文件 中，业务代码通过配置读取，使机器人名称、表达方式和安全边界能够在不修改对话逻辑的情况下 切换。模型被要求返回 reply_text、style、emotion 和 motion 字段，服务端再根据用户输入校正情 绪与动作，避免负面情绪被误配为 happy。若 Ollama 不可用或返回解析失败，服务端使用规则回 复兜底并标记状态。
TTS 服务提供 Windows SAPI 和 GPT-SoVITS 两个后端。所有输出在服务端统一为 ESP32 可播放的 16 kHz、16 bit、单声道 WAV。当前后台 AI bridge 默认采用 Windows SAPI；GPT-SoVITS 已在调试接口生成过规范 WAV，但未完成当前整机的持续联调。ESP32 下载完整 WAV 后解析 data 区块并通过 I2S 送往 MAX98357A 播放。

### 4.4 动作队列与同步插值

服务端 motion 字段支持 happy、shy、comfort、curious 和 none。ESP32 在机器控制开关开启 时把相应意图投递到长度为 8 的 FreeRTOS 队列。动作任务从队列中取出命令，按照目标姿态和当 前姿态之间的最大角度差确定插值步数，再同步更新五个通道，避免网络、录音或播放任务直接执 行长时间阻塞动作。当前 comfort 和 curious 在执行端共用 curious 动作，属于第一版动作映射， 后续应结合整机外观和用户体验继续细化。


图 4-1 语音交互与动作执行数据流

### 5 个性化设计

### 5.1 角色与回复风格

当前“糯糯”人设描述其为温暖、活泼、略带傲娇的毛绒小龙。提示词同时约束回复应使用简体 中文、尽量短、适合语音播放，不进行医学诊断或承诺治疗效果；当出现明显危险、自伤或急症内 容时，应鼓励用户寻求现实中的可信任人员或专业帮助。服务端当前提供 cute 和 encourage 两种 情境风格，并保留最近四轮对话作为短期上下文。

### 5.2 可配置项目

可配置内容 | 配置位置 | 当前状态
角色名称与提示词 | server/prompts 与环境变量 | 已提供入口
LLM 模型、超时与回 复风格 | server_config.py / 环境变量 | 已提供入口
ASR 模型、beam、 best_of、热词 | server_config.py / 环境变量 | 已提供入口；热词默认关闭
TTS 后端、参考音频与 语言 | server_config.py / 环境变量 | 已提供入口
端点检测阈值与会话 时间 | main/network_config.h | 已提供入口
舵机通道、角度范围与 主页 | main/robot_config.h | 已提供入口，待机械校准
触摸输入 | main/robot_config.h | 代码预留，默认关闭

需要注意的是，配置入口不等于已经完成效果验证。例如，GPT-SoVITS 后端可由配置启用， 但当前后台服务尚未运行该 API；触摸输入已有 GPIO 和动作映射，但未接硬件时默认关闭。论文 中应将这些内容写为“可配置能力”或“待验证扩展”，而不能表述为成品功能。

### 6 开发过程、测试与讨论

### 6.1 录音和网络链路的迭代

项目早期采用固定 5 秒录音。该方式在短句场景中会引入额外静音和等待，而长句或停顿场景 又可能出现截断。为此，固件保留固定时长函数作为回退，并新增端点检测函数，通过环境噪声基 线、动态开始/停止阈值、80 ms 开口确认、300 ms pre-roll、最短录音时长和连续静音结束判定控制 上传边界。该功能已经写入当前代码；需要在短句、长句、停顿和不开口场景下进一步采集串口日 志和录音样本，才能形成端点完整率结论。
一次测试中，欢迎音播放后系统直接进入本地命令词模式，表面现象像是端点检测没有执行。 排查后发现根因是 ai_bridge_ready 为 false 时触发了静默回退，且旧日志在 ready 判断前就打印了 “准备录音”。后续修改为每次唤醒前检查 Wi-Fi 和 AI bridge 状态，并输出服务器地址和失败原因。 该问题说明联网系统需要可观测性，不能仅依赖静默回退。

### 6.2 ASR、回复与 TTS 的迭代

ASR 从 tiny 调整为 small 后，解码参数修改为 beam_size=5、best_of=5，关闭跨片段文本条 件，并增加繁体转简体。完整提示词和过强热词曾在短而含糊的录音中引发幻听，因此当前默认关 闭，仅保留受控实验配置入口。非正式旧录音复查显示 small 模型对部分结果有改善，热启动单条 识别约 1.6～1.8 秒；这只是开发观察，不能替代标准语料的统计实验。 回复生成方面，项目从规则话术逐步增加 Ollama 本地模型、角色提示词、短期上下文、情绪 字段和动作字段。人设文件从业务代码拆出后，能够在不重写服务逻辑的情况下切换机器人形象。 TTS 方面，Windows SAPI 被保留为稳定回退；GPT-SoVITS 适配了 api_v2 参数和 WAV 规范化， 单独调试接口已成功生成可识别的 16 kHz WAV，但当前整机端到端效果仍待验证。

### 6.3 动作与硬件问题的迭代

为适配四脚加尾巴，动作层从早期的少路、阻塞式控制调整为五通道配置和独立 FreeRTOS 动 作任务。公开动作函数仅负责入队，执行任务负责插值和 PWM 写入。统一工程的五路版本已经编 译，且 v2 固件曾成功烧录；实际复测中，GPIO8、GPIO9、GPIO10 未连接的触摸输入处于悬空状 态 ， 持 续 误 触 发 动 作 并 占 满 队 列 ， 导 致 正 常 串 口 舵 机 命 令 看 似 无 效 。 修 复 方 案 是 将 TOUCH_INPUTS_ENABLED 默认设为 false，并使关闭机器控制时清空待执行动作和请求复位。 修复后，用户实际测试了通道 0 的 servo fl 80 和 servo fl 100 指令，确认动作只入队一次且舵 机运动符合预期。这证明了统一工程中 PCA9685 通道 0、动作队列和悬空触摸修复的可用性，但不 证明其余四通道、组合动作或五机大电流供电已通过。

### 6.4 当前测试结果与待补实验

测试项 | 当前结果 | 论文表述边界
单舵机台架 | 通道 0 正常运动，无尖叫 | 已实测；仅单机
五路动作代码 | 队列与插值编译通过 | 不可写成五机已稳定运行
历史 AI 端到端 | 存在 PCM 上传、200 响应和 WAV 下载日志 | 证明历史链路通，不代表最新固 件
ASR small | 四段旧录音的非正式改善观察 | 不可报告正式 CER
GPT-SoVITS | 调试接口生成规范 WAV | 当前整机联调待完成
连续对话 v1 | 代码与编译完成 | 尚未烧录实测

后续实验应首先建立带人工标准文本的 20～50 条语料，在安静和普通室内噪声、20 cm 和 50 cm 距离下记录唤醒成功率、误唤醒率、CER、整句正确率和端点完整率。响应速度应记录说话结束、 上传完成、ASR 完成、LLM 完成、TTS 完成、下载完成、播放开始和动作开始时间，并报告 P50 与 P90。硬件部分应逐通道验证 1 至 4，再从两机并发逐步扩展到五机，记录峰值电流、异常复位、 温升、动作噪声和机械卡滞情况。

### 7 结论

本文完成了毛绒陪伴机器人语音与动作系统的初步设计与实现。系统采用 ESP32-S3 与电脑端 AI bridge 分工：前者负责本地音频采集、唤醒、网络通信、播放和动作执行，后者负责 faster-whisper 识别、Ollama 对话和 TTS 合成。硬件方案明确了 INMP441、MAX98357A、PCA9685 和五路舵 机的通信关系，并提出了 2S 电池经 5V 稳压后使用星形分支、舵机独立大电流支路和所有模块共地 的成品供电结构。
在软件实现方面，系统已具备端点检测录音、PCM 上传、结构化服务端返回、动态 WAV 下 载播放、角色提示词加载和动作队列控制等能力。开发过程中针对固定时长录音、AI bridge 静默回 退、ASR 幻听、角色一致性、TTS 格式、触摸悬空误触发和阻塞式动作等问题进行了多轮修改。 当前已完成单舵机通道 0 的实际验证，并保留了历史语音端到端日志。 本项目仍处于原型迭代阶段。后续需要完成五路舵机与电源系统的实测、连续对话最新版固件 的烧录、端点检测的系统化场景测试、标准 ASR 语料评估、GPT-SoVITS 整机联调及用户体验评 价。只有在获得重复测试记录后，才能对识别准确率、延迟、稳定性和陪伴体验形成量化结论。 参考文献
[1] Espressif Systems. ESP32-S3 Series Datasheet[EB/OL]. https://www.espressif.com/sites/default/files/documentation/esp32-s3_datasheet_en.pdf.
[2] NXP Semiconductors. PCA9685 16-channel, 12-bit PWM Fm+ I2C-bus LED controller[EB/OL]. https://www.nxp.com/docs/en/data-sheet/PCA9685.pdf.
[3] TDK InvenSense. INMP441 High Accuracy Low Power Digital Output MEMS Microphone[EB/OL]. https://invensense.tdk.com/wp-content/uploads/2015/02/INMP441.pdf.
[4] Analog Devices. MAX98357A/MAX98357B PCM Input Class D Audio Power Amplifiers[EB/OL]. https://www.analog.com/media/en/technical-documentation/data-sheets/MAX98357A-MAX98357B.pdf.
[5] Radford A, Kim J W, Xu T, et al. Robust Speech Recognition via Large-Scale Weak Supervision[EB/OL]. arXiv:2212.04356, 2022.
[6] SYSTRAN. faster-whisper: Faster Whisper transcription with CTranslate2[EB/OL]. https://github.com/SYSTRAN/faster-whisper.
[7] Ollama. Ollama Documentation[EB/OL]. https://docs.ollama.com/.
[8] 毛绒治愈机器人 PRP 项目组. AI Bridge 录音端点检测模块说明[Z]. 2026.
[9] 毛绒治愈机器人 PRP 项目组. 五舵机硬件集成与语音量化评估计划[Z]. 2026.
致谢

感谢指导教师在课题方向、系统设计和论文撰写方面给予的指导，感谢参与项目测试与讨论的 同学提供意见，也感谢在硬件接线、语音录音和功能验证过程中给予帮助的人员。后续将继续完善 实验记录，使本研究从可运行原型逐步发展为具有完整证据链的项目成果。

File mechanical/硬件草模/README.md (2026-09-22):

# 硬件草模（当前交付入口）

用户已改为自行设计骨架与连接。本文件夹从上一版装配中提取已有硬件简化实体，仅供 SolidWorks 外形、尺寸和空间布局参考；mechanical/v0 保留作历史，不再代表当前骨架方案。

## 文件与尺寸

全部单位为 mm。下表是模型包络尺寸，不等于全部已实测。

| 文件 | X × Y × Z | 已知限制 |
|---|---|---|
| 01_SG90_舵机.step | 32.5 × 12 × 27.3 | 含安装耳、两个 Ø2.2 孔，孔距 27.8；主体平面 23 × 12；未精建花键、舵盘、线材 |
| 02_ESP32-S3_开发板.step | 63.389 × 27.94 × 11.6 | 长度含天线；板厚 1.6 和元件高度 10 为暂定值 |
| 03_PCA9685_驱动板.step | 60 × 25 × 11.6 | 板厚和元件高度暂定；未建安装孔 |
| 04_电池_68x36x18_型号待核对.step | 68 × 36 × 18 | 新图 3000mAh 与旧订单 2000mAh 不一致；未含出线和插头 |
| 05_降压板_60x30x16_型号待核对.step | 60 × 30 × 16 | 新图 CR-D4080P 与旧订单小板不一致；仅外包络，未建孔 |
| 06_MAX98357A_功放_高度暂定.step | 18 × 19 × 10 | 高度暂定；未建孔 |
| 07_扬声器_35x25_厚度暂定.step | 35 × 25 × 7.8 | 厚度按图中 6.8 与 1.0 叠加预留，需实测；未细建边框、振膜 |
| 占位_未定尺寸/08_INMP441_仅20x20x10占位.step | 20 × 20 × 10 | 全部为暂定占位尺寸，无可靠实物尺寸依据 |

图片尺寸与孔位证据见 ../v0/硬件尺寸与孔位核对.md。除 SG90 外，草模不含可用于定位加工的安装孔。功放图片上孔距 12.6、降压板图片孔距 53 × 24 仅是待核对信息，未补入模型。

## SolidWorks 使用

1. 文件 → 打开，选择所需 STEP；导入后可另存为 SLDPRT。文件是导入实体，没有原生草图或特征历史。
2. 每个模型的 XY 外形中心为原点，最低面 Z=0；板卡元件侧朝 +Z，舵机输出轴朝 +Z。
3. 装配时重复插入 SG90 即可放置五路舵机；同型号降压板可按实际数量重复插入。
4. 00_硬件草模总览_非装配布局.step 将八种草模排成展示网格，方便同时查看，不代表机器人安装位置。

USB、排针、接插件和线材没有精确建模，实物布局需另留插拔和弯线空间。本批文件为外购硬件参考模型，不是待打印的骨架零件。

## 核验

八个单件均通过有效单实体、提取前后体积一致及 STEP 导出回读检查，结果见 提取核验.json。提取仅改变坐标与朝向，并将板卡相接的包络体合并；没有重新设计硬件外形。尚未进行本批单件的 SolidWorks 逐件导入或实物尺寸验收。

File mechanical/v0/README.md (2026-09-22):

# PRP 五舵机骨架 V0 — 试装与评审版

**当前不是承重验收完成的打印定版。** 已依据商品图片创建真实B-Rep实体与分件STL；SKU、部分高度和舵盘孔位仍待实物核对。几何检查的实际结果见 `output/validation.json`，硬件证据见 `硬件尺寸与孔位核对.md`。

## 设计范围

- PLA；每个单独打印件小于200×200×200。整体装配不需要在打印机里一次成型。
- 主框架150×94×65；上层降压板最高参考到90。包含脚、扬声器和尾臂后的包络为220.7×166×104，明显大于初始70×50×50。
- 保留5只SG90、1块ESP32-S3、1块PCA9685、1块电池、2块降压板、功放和喇叭安装位置；麦克风和电源附件为明确标注的预留空间。没有假称未知充电/触摸模块均已完成专用安装。
- 底层可拆电池托，第二层主控/舵机驱动，顶层两路降压与小附件。电池供电后仍要给ESP32的5V/VIN提供合适电源；不能靠USB代替成品供电路径。两块降压器的输出不能直接并联。
- 四腿采用独立M4金属轴、金属轴套和连杆。承重路径为脚→腿→轴套/轴→双侧支座→主框架；SG90用原装舵盘驱动连杆。独立腿轴减少舵机径向载荷，**不减少需要的驱动扭矩**。
- 每腿只有一个摆动自由度，适合先验证站立和小幅姿态；不承诺实现任意方向行走或稳定步态。

## 文件与使用方法

| 文件/目录 | 用途 |
|---|---|
| `generate_frame.py` | 可重建的几何源程序；尺寸定义在构造调用中，修改后重新执行检查 |
| `requirements.txt` | CAD生成依赖；不属于ESP32固件依赖 |
| `output/cad_parameters.json` | 本版尺寸摘要，不是驱动所有几何的外部参数配置文件 |
| `output/PRP_V0_with_hardware.step` | 全装配评审，含标记REF的硬件简化包络；不能整体打印 |
| `output/PRP_V0_frame_only.step` | 打印结构的装配位置评审；也不是一体打印文件 |
| `output/step_parts/` | 每个打印件的独立STEP；坐标保留装配位置 |
| `output/stl_parts/` | 每个打印件已平移到打印平面；V0完整件，仅在试装通过后使用 |
| `output/stl_trial/` | 优先打印的小样：舵机安装板、孔径、轴套、夹具、原装舵盘适配件 |
| `output/validation.json` | 实体有效性、STL闭合性、尺寸、干涉和实心质量估计 |
| `output/assembly_preview.png` | 由真实几何渲染的预览，绿色等半透明块是硬件参考包络 |

用已安装CadQuery的Python执行 `python generate_frame.py`。本轮隔离生成依赖位于用户缓存，不改项目固件环境、不启动网络服务。STEP可由SolidWorks直接打开；导入实体不会自动拥有SolidWorks原生草图/拉伸特征树，修改复杂尺寸建议改几何源程序后重新导入。不得将原始STL统一缩放来修孔，否则所有安装尺寸一起改变。

## 关节与标准件

| 项目 | 首版建议 / 数量 | 注意 |
|---|---|---|
| 主关节轴 | M4×35半牙螺栓、垫圈、防松螺母，各4套 | 轴套接触范围应全部为光杆，核对实际螺栓光杆长度；不是3D打印轴 |
| 轴套 | 金属管外径6、内径4、长10，共4 | 轴套固定，腿在外径上转动；腿厚9.5、打印孔6.25，径向和端面间隙用小样验证 |
| 轴向隔套 | 内侧3.5、外侧2.5厚，各4组 | 用合适金属薄垫/隔套组合。固定内宽16=3.5+10+2.5；锁紧螺母不应夹住旋转腿端面 |
| 连杆销 | M2小螺栓、薄垫、防松螺母，8组 | 连杆2厚，与舵盘转接件/腿之间留活动间隙，不能锁死转动副 |
| 舵机固定 | M2螺栓/螺母，10组 | SG90原孔2.2；打印板2.4孔，不能硬塞M3 |
| 支座固定 | M3螺栓/螺母，16组 | 每个独立腿座4个，通孔3.3；螺栓长度按实际叠厚选取 |
| 板层及滑座固定 | M3螺栓/螺母/垫片，按装配 | V0均按通孔和背面螺母，不把3.3孔当自攻底孔；顶部长螺栓/拉杆须核对长度和工具空间 |
| 舵盘连接 | 使用SG90原装舵盘和原中心螺丝 | 不打印花键。适配件中的长槽只是试装结构，孔位/高度未经实物确认 |
| 电池固定 | 10宽魔术贴绑带2条、薄软垫 | 不用尖螺丝直接顶电池，不挤压电芯或引线根部 |
| 小PCB与线束 | 绝缘垫、合适夹具、细扎带 | 不能挡麦克风声孔或压焊点。试装夹具T03按实际板厚修订后再批量打印 |
| 脚底 | 软橡胶防滑垫4片 | PLA脚底本身不保证摩擦系数 |

以上是新增机械标准件需求，不是已购买库存。通孔、螺母及维修工具的可达性仍需实装确认；装配时先在主框架未封顶前穿好侧壁螺母。

## PLA打印起始参数

- 假设0.4喷嘴、0.20层高。承重框架与腿座建议5～6道壁、上下各至少5层、35～45%填充；薄连杆和舵盘适配件建议实心。
- 电子托板可用4道壁、25～35%填充。实际薄板/薄筋由外壁占主导，提高填充率不能弥补错误打印方向或尖角裂纹。
- STL已经放到Z=0。主框架底面朝下；腿和连杆平放，主弯曲受力方向在层面内。腿座按文件朝向放置，并在桥接/悬挑下使用可去除支撑，避开轴孔和贴合面。
- 腿座是试装版的厚实设计。实际质量以切片软件为准，CAD实心密度估算不是实际打印重量。
- 顶层降压器周围不得塞紧棉花；PLA的温升/蠕变必须在全装配环境验证。不要把商品标称8A当作毛绒封闭环境的持续输出能力。
- 先打印T01/T02/T04/T05并记录孔径、装配阻力和间隙；通过后先做单腿，再决定整套打印。T03用于小板夹持试验。

## 承重与扭矩边界

设整机质量M kg，最不利时两腿均分载荷，腿长52 mm，偏离竖直15°，两端曲柄均10 mm（近似1:1），动态系数2、传动效率暂取0.7：

`每只舵机所需扭矩 ≈ (M/2) × (5.2×sin15°) × 2 / 0.7 = 1.92M kgf·cm`

M=0.5 kg时约0.96 kgf·cm，M=0.7 kg时约1.35 kgf·cm。这是理想分载下的设计估算，未包含所有偏载、毛绒阻力和冲击；商品堵转扭矩也不能作为连续可用扭矩。实际重心可能让一条腿承担大于一半重量。静止竖直腿理论力臂接近零，不代表运动时仍无需扭矩。

本版没有设置已经验证的“最大承重”。如实物扭矩/电流/温升不过关，应更换舵机或增加机械减速/减载，并修改安装座，不能通过提高PLA填充率解决舵机扭矩不足。

## 验证与定版门槛

1. 台账中的SKU、孔位、板高、线束和舵盘尺寸完成实物核对。
2. 无电单腿试装：轴旋转顺畅、无明显晃动，连杆不卡，手动小幅摆动不碰加强筋。原装舵盘适配未通过前不带电加载。
3. 先以沙袋/砝码逐级加载一个关节，记录载荷、挠度、保持时间和卸载残余变形；再做四腿静态站立。不得直接拿已装电池的整机做跌落试验。
4. 低速小角度逐步上电，记录电压、舵机峰值/持续电流、温升和噪声。固件当前保守限位不自动等于新机构限位，需重新校准主页和方向；本轮不烧录。
5. 包含毛绒、线束、接头和填充物的最终状态再测热、卡滞和语音干扰。数值检查不包含柔性毛绒。

静态零干涉、离散姿态无碰撞和闭合STL只能证明对应模型的几何性质；不是有限元分析、连续运动证明、承重等级或实物验收。

## 本轮验证记录

- 32个分件均为有效单实体，STL闭合且面朝向一致；5种试装小样STL闭合。
- 静态打印件、硬件参考包络两两检查均无体积大于0.05mm³的干涉；四腿在±7.5°、±15°离散姿态无打印件干涉。这不是连续扫掠验证。
- 全装配STEP独立回读：56个实体、有效、包络220.7×166×104。
- SolidWorks 2024已实际打开并保存 output/PRP_V0_with_hardware.SLDASM，保留同目录STEP引用。属于STEP导入装配，不是原生草图特征历史，也尚未建立运动配合。
- CAD实心PLA估算368.26g；填充后的重量需切片计算，电子件/金属件/毛绒未计入。
- platformio run成功（RAM14.8%、Flash72.2%）；只作为项目要求的构建检查，不代表已烧录或承重/机械实测。本轮未修改固件与服务端逻辑。

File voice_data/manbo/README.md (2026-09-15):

# manbo：唯一当前训练数据

更新：2026-09-15。实验名统一为 `manbo`。本目录是当前有效输入；旧 `nuonuo_mambo_*`、`manbo_narrator_*` 素材/训练产物已移入回收站，不再使用历史路径。

## 只需要认这四项

| 用途 | 文件链接 | 完整路径 |
| --- | --- | --- |
| 39 段训练音频，001～039 顺序不变 | [clips](E:/Projects2026/Prp_voice_servo_unified/voice_data/manbo/clips) | `E:\Projects2026\Prp_voice_servo_unified\voice_data\manbo\clips` |
| 每段对应的中文，训练/校对的权威标注 | [clips.list](E:/Projects2026/Prp_voice_servo_unified/voice_data/manbo/clips.list) | `E:\Projects2026\Prp_voice_servo_unified\voice_data\manbo\clips.list` |
| 完整连续的中文原音频，不是拼接切片 | [full_audio.wav](E:/Projects2026/Prp_voice_servo_unified/voice_data/manbo/full_audio.wav) | `E:\Projects2026\Prp_voice_servo_unified\voice_data\manbo\full_audio.wav` |
| 与完整音频对应的整段中文，派生输出 | [full_text.txt](E:/Projects2026/Prp_voice_servo_unified/voice_data/manbo/full_text.txt) | `E:\Projects2026\Prp_voice_servo_unified\voice_data\manbo\full_text.txt` |

`clips.list` 每行格式：`绝对音频路径|说话人|ZH|中文文本`。不需要为每个 WAV 再创建单独 txt。文字来自用户 2026-09-15 10:13:25 最后保存的校对稿，迁移没有重新识别或擅自改写文字。

完整音频为 188.10 秒、44.1kHz/16bit/单声道；39 段切片为32kHz/16bit/单声道，共197.85秒。多出的9.75秒是每段末尾追加250ms静音，不是新增语音，也不能宣称补回了缺失字音。此次只迁移/简化文件名，未改变分句边界或音频内容。日语不在此训练集内。

`dataset.json` 是迁移溯源和 SHA256 校验记录，不是第二套标注。其初始标注哈希只代表迁移时刻，之后用户继续校对会改变标注哈希。

## 如何打开和保存

在 PowerShell 执行：

```powershell
powershell -NoProfile -ExecutionPolicy Bypass -File E:\Projects2026\Prp_voice_servo_unified\server\tools\start_manbo_training.ps1
```

预期：仅启动训练主界面，提示 [训练页 9874](http://127.0.0.1:9874/)，不会自动打开浏览器、训练模型或切换机器人声音。端口已占用时脚本拒绝重复启动。请在自己的外部浏览器中打开该地址。

在 `0-数据集获取工具 → 0d-语音文本校对` 确认路径是本目录的 `clips.list`，点击开启校对工具，然后在同一外部浏览器打开 [校对页 9871](http://127.0.0.1:9871/)。只保留一个校对标签页；旧程序仍有全局页码问题，不能多窗口同时校对。

修改后点击 `Submit Text`，先保存再翻页。由本启动入口派生的校对服务保存 `clips.list` 时会同步重新生成 `full_text.txt`。不要单独修改派生整段稿；不要在训练正在读数据时修改标注。若手动更改 `.list`，该保存钩子不会自动运行。

开始新训练前需要重新做 `1A` 特征提取，再做 `1B` 两阶段训练，最后 `1C` 试听；本轮仅整理数据和入口，未执行新训练。不要复用已删除的旧训练缓存。训练产物将由 GPT-SoVITS 在安装目录的 `logs\manbo` 和相应权重目录生成，而不是写回这四项输入。

## 清理与保护

53项旧 manbo 素材、模型、日志和缓存（约6.94GB）已移入 Windows 回收站，可恢复，未清空回收站；这不等于磁盘已释放6.94GB。审计清单在 `E:\Projects2026\Prp_voice_servo_unified\docs\工作留档\manbo_cleanup_20260915.json`。

三月七目录、本人参考音频/配置、官方预训练模型及必要依赖未删除。三月七包是 RVC 格式，保留它不代表已接入 GPT-SoVITS。此前个人声音是参考音频零样本克隆，不应误称为训练出的权重。

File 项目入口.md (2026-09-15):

# PRP项目：以后只从这里进入

唯一工作根目录：`E:\Projects2026\Prp_voice_servo_unified`。

2026-09-15已将用户指定的另外两个目录实际迁入此处，不是快捷方式或复制一份。当前固件、服务器、训练素材和论文初稿原位置未变。没有把旧代码混入当前`main`或`server`。

| 你要找什么 | 现在的完整路径 | 使用规则 |
| --- | --- | --- |
| 当前ESP32代码 | `E:\Projects2026\Prp_voice_servo_unified\main` | 后续功能开发使用这里 |
| 当前电脑语音服务器 | `E:\Projects2026\Prp_voice_servo_unified\server` | ASR、回复、TTS与启动脚本 |
| 当前训练数据 | `E:\Projects2026\Prp_voice_servo_unified\voice_data\manbo` | 唯一当前中文切片与标注 |
| 最新论文初稿 | `E:\Projects2026\Prp_voice_servo_unified\论文初稿` | 保留已有正式版、历史与排版检查，不用原始资料覆盖 |
| 当前文档与进度 | `E:\Projects2026\Prp_voice_servo_unified\docs` | README索引、task_progress、结构地图是现行依据 |
| 旧舵机Arduino工程 | `E:\Projects2026\Prp_voice_servo_unified\legacy\Prp_servo_arduino` | 原`E:\Projects2026\Prp`；历史参考，不作为现行主工程 |
| 原college项目资料 | `E:\Projects2026\Prp_voice_servo_unified\archive\PRP_原始项目资料` | 原`E:\college\毛绒治愈机器人PRP`；PPT、调研、材料清单、发票、旧语音源码、固件备份全部保留 |

## 打开方式

文件资源管理器打开当前根目录：

```powershell
explorer.exe "E:\Projects2026\Prp_voice_servo_unified"
```

VS Code可打开 [PRP.code-workspace](E:/Projects2026/Prp_voice_servo_unified/PRP.code-workspace)，完整路径：`E:\Projects2026\Prp_voice_servo_unified\PRP.code-workspace`。其中只配置一个当前根文件夹，不再并列多个老项目入口。

原两个顶层目录已不存在，旧快捷方式、最近打开记录、历史任务工作目录需要改指新位置。旧`legacy\Prp_servo_arduino\src\Prp_servo_control.code-workspace`保留原文，其中跨目录引用已过时，不要用它打开当前项目。旧`.pio`缓存也保留作原始快照，路径已经变化，不表示旧工程在新位置已重新编译。

## 保留与验证

- 旧舵机工程182文件，29,960,389字节；原college资料1046文件，356,841,473字节。迁移前后逐文件SHA256核对一致，共1228文件。
- 旧舵机仓库保留独立`.git`及原提交`9e0014c`，原来3项修改和1项未跟踪工作区文件保持不变，没有替用户提交/重置旧仓库。
- 首次目录移动遭Windows拒绝并部分迁移，随后按清单逐文件续迁；核验无缺失、无覆盖，最终仅删除空的旧目录。文件没有被删除或送入回收站，需要撤销时按迁移清单回迁，不要依赖旧路径。
- 完整逐文件校验清单仅本地保存于 `E:\Projects2026\Prp_voice_servo_unified\.local_migration\20260915\files.json`，不上传发票相关文件名等细节。

## 本地集中与Git不是一回事

私有远程：[GitHub项目仓库](https://github.com/nianchu3110988968/Prp_voice_servo_unified)。每阶段提交并推送当前代码、文档和整理工具。

`legacy`、`archive`、`.local_migration`暂不上传；原因是包含旧独立仓库、发票、历史固件和第三方源码，先保留完整本地资料，不未经分类审查整包推送。当前仓库的Git提交记录此次迁移规则与路径，但**不是这两份本地归档的云备份**。音频/模型/网络密码仍按原规则留本地。

GPT-SoVITS运行环境仍在 `E:\AI\GPTSoVITS\GPT-SoVITS-v2pro-20250604`，属于外部依赖，本轮没有搬动它，也没有更改模型/服务配置。所谓统一，是把你点名的三个项目目录收敛到当前根目录，不是搬动所有软件安装目录。

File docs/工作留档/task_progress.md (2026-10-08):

# 任务进度记录

## 2026-10-09：新增按需工具与权限请求 skill

- 按用户要求创建全局 `request-scoped-access`，明确区分缺工具、未连接、权限拒绝、协作约定和普通故障；要求提前说明证据、用途、最小范围、开通/撤销方法、验证与手动替代，并保留用户决定权。已有有效授权不重复请求，提出请求不代表权限已授予。
- 全局 AGENTS 已加入触发入口；同步项目工作记忆与结构地图。skill 的权威文件位于用户 `.codex/skills`，不在本项目 Git 范围；本阶段项目提交仅收录三份文档的本次增量。
- 已用文件工具完成结构/frontmatter 字段/命名/长度/UI 元数据静态检查，并人工复核已有授权、缺失接口、用户拒绝、普通故障和连接后验收场景；未运行 Python quick_validate.py，未进行真实连接验证。未修改业务代码，不涉及固件构建。
- 当前未提供可控制 VS Code 集成终端的工具，原生桌面控制未启用；MCP 仅为候选连接方式，尚未选型、安装或配置。可见终端、外部浏览器与硬件授权边界不变。
- 本阶段按已授权流程独立提交并推送，实际结果以 Git 返回和聊天交付为准；保留全部既有未提交修改。

## 2026-10-09：桃金娘首轮训练输入与启动步骤已准备（尚未训练）

- 用户确认 v3 切片文字可用于下一步。按项目 3～10 秒指南，从 38 段中选 34 段、199.55 秒生成 `semantic_v3/training.list`，排除完整但不足 3 秒的 024/026/034/036；保留全部原 WAV。生成 `training_manifest.json`、`full_text.txt` 和 `TRAINING_START.md`，实验名定为未占用的 `myrtle_zh_v1`，版本 `v2ProPlus`。
- 本机 GPT-SoVITS runtime、webui、v2ProPlus G/D、GPT s1v3 及中文 BERT/HuBERT 底模均存在；9874/9872/9880/8000 当前未监听，RTX 4060 Laptop 8 GB 查询时占用约 449 MB。启动脚本在下载目录 inspection，复用既有 manbo 启动环境但只预填桃金娘素材；PowerShell 语法解析 0 错，清单 34 行、哈希/文件/文字/时长/格式核验通过。
- 当前仅准备了输入和启动说明，未在用户 VS Code 可见终端运行脚本，未开启训练 WebUI、1A 格式化、1B 训练、1C 推理，也未生成权重或烧录。后续由用户在可见终端启动，在外部浏览器完成 1A→SoVITS→GPT→试听；录音/清单/模型不入 Git。本阶段没有修改项目业务或固件代码，因此未执行 platformio run。

## 2026-10-09：桃金娘语义切片按用户试听反馈修订为 v3（待复听）

- 当前交付改为下载目录 `PRP_410582114/semantic_v3`：38 段 WAV、208.55 秒，单段 1.70～9.88 秒；v2 保留为历史对照。007“啊”改“欸嘿嘿”，022“咦”改“欸”；009 只删除文字中的“啊哈哈”，音频恢复原范围，008 未改；015 末尾的“不过”移入 016。用户最后确认 029/030 各保留两句合段，约 4.30/5.90 秒；临时拆分的四个 WAV 已移到 inspection 历史目录，不在当前切片文件夹中。
- 校验：38 个 WAV 均与原连续音频相应 PCM 完全一致；008/009/029/030 的音频与 v2 哈希相同；试听页有 38 个播放器，校对表 38 行且编号/路径对应。排除片头旁白后，-35/-30/-25 dB 无高能量漏切。4 段短于 3 秒，均在报告中标记。
- 用户需重点复听 015/016 的“不过”和 009 的纯文字改动；自动校验不等于耳听验收。`semantic_DRAFT_DO_NOT_TRAIN.list` 仍仅为草稿，正式训练 `.list` 待校对确认后生成。本次未训练、未修改项目业务代码或固件、未烧录，录音和模型仍不入 Git。

## 2026-10-09：桃金娘素材按中文语义重新切片（待听审）

- 下载目录 `PRP_410582114/semantic_v2` 已生成 38 段语义切片（32 kHz、单声道、16 bit，合计 208.67 秒，单段 1.70～9.88 秒），旧 48 段保留作历史对照。第 3/4 段切点移到“我就被占便宜了”之后的停顿，避免拆开“虽然……但是……”；另有本地试听校对页 `semantic_review.html`。候选文字依据画面字幕和旧 ASR 整理，灰色旧识别上下文已统一简体，包括“睡著→睡着”；它仍可能跨句、含错字，不能直接作训练标注。
- 静态校验：38 个 WAV 的 PCM 与原连续音频对应区间一致、无缺文件；排除片头旁白后，在 -35/-30/-25 dB 检查中无高能量漏切；候选文字与旧 ASR 上下文通过 OpenCC 简体检查。开头语气词、笑声边界、两句战斗台词合并及 4 段短于 3 秒的完整台词仍需逐段试听。
- `semantic_DRAFT_DO_NOT_TRAIN.list` 仅为候选，不作为正式训练输入；完成逐段语音与文字校对后再生成正式 `.list`。本次没有训练、烧录或修改项目代码；音频留在下载目录，不纳入 Git。

## 2026-10-08：两分钟答辩交互流程图

- 为答辩生成3840×2160 PNG及对应SVG，按机器人采集、电脑ASR/LLM/TTS、机器人下载播放展开；动作指令从LLM单独分出，并标注语音起播触发和整机待验证。
- 新增docs/答辩材料/README.md，提供约30秒配套讲解及图示范围；同步文档索引与结构地图。已视觉检查PNG中文、连线及布局，SVG保留矢量文字与形状。
- 本轮只制作说明图，未修改业务代码、启动服务、构建、烧录或测试硬件；既有词库匹配问题和动作验收状态未改变。仅归档本轮图片与文档增量，保留其他未提交修改；本地提交与远程推送以实际Git结果为准。

用于切换 agent 或中断后快速接续。每次完成阶段性任务后，用简短语言更新本文件。

## 2026-10-08：重启后状态检查（当前修复已加载，真实词库匹配仍失败）

- 只读核对当前bridge PID188136，项目根目录正确，Python为Scoop Python3.13.11；运行source_sha256与磁盘一致（dc79ea306161dbba1cc5415316691811a002bf6e4a3b0c251a46abcdb6a499b0），协议independent-phrase-motion-v1。475d536的120秒历史过期与词库诊断接口已加载，不再沿用9月30日“服务待重载”状态。
- ASR启动预热ok；LLM启动预热30秒读超时，health仍保留failed。实际Ollama qwen2.5:3b最小推理HTTP200返回“正常”，耗时27855ms；随后模型已加载。Ollama日志显示RTX4060 Laptop GPU、37/37层卸载，不能将超时写成模型缺失或CPU回退。
- 当前New_ManBoo/曼波音色voice_ready=true，9880接口可达、权重已加载；actual_tts=not_tested，本轮未生成或试听新音频。当前Excel与已发布manifest的源指纹一致，8个WAV均存在且内容SHA匹配。
- 使用已加载的POST /debug/phrase-match依次实测“曼波，过来！”、“坐下”、“漫播，过来”，全部HTTP200/status=miss，entries=8，match_ms分别907/586/283。前两项为Excel原文，证明当前服务端语义匹配仍未通过；该接口经过当前激活缓存和生产匹配器，不跑ASR/TTS/历史/ESP，因此不能仅归因于识别错字或板端协议。此为3项抽查，不冒充完整8条/否定/乱序重复验收；本轮未修改匹配逻辑。
- EXE仍为此前验证包，SHA256 ce89200090a1dbf5e7224bae9eb3a368882a4ece475defd1f1450173ddd5be80。固件产物仍为已通过构建的manbo-welcome-v1，SHA256 bef7f365b0ffa5ff12720de9448f0f3b32622bb3680ebc198b55dff427339730；未新增构建/烧录。实际唤醒模型仍为“你好小智”，“你好曼波”尚未实现；新欢迎音源码为“叫我干嘛”。
- 未发现本日串口日志；本轮未占用串口，当前USB端口和板上版本待用户VS Code可见终端核对，不默认COM7。工具无法直接连接该终端，未隐藏启动服务/监视器；未操作舵机，外部电源断开/机器控制关闭要求继续有效。
- Git远程实时查询成功，检查时origin/main为0018cfe，本地475d536尚未推送；本次仅选择性提交此状态段落，保留全部既有未提交改动。提交与推送最终结果以本轮Git输出为准。下一步优先修复真实语义匹配并做原文/同音/否定/反义/回复正文/无关输入对照，再核对串口/板端版本和欢迎音、普通语音及词库播放；不为此重打包EXE或重复生成缓存。
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

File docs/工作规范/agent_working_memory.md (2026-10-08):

# Agent 工作记忆

## 工具与权限缺口沟通（2026-10-09）

- 遇到能力缺口，使用全局 request-scoped-access skill：先区分工具缺失、未连接/认证、权限拒绝、协作约定与普通程序故障，再主动提出具体接入或授权方案。说明缺口证据、用途、最小范围、开通/撤销方式、能力验证及手动替代；已有授权不重复请求。
- VS Code 可见终端限制仍有效；文件编辑工具或 Codex 自带终端不能当作 VS Code 终端控制。当前工具清单未提供该接口、原生桌面控制未启用，不代表用户未授权电脑操作。VS Code MCP 仅是待核实的候选，须实际支持终端交互；用户同意不等于连接成功。
- 本次仅建立沟通规则，没有安装 MCP、修改权限配置或取得新的终端执行授权。以后工具/连接变化时重新核对，不把当前缺口写成永久不可用。

本文件记录本项目中需要长期遵守的协作方式和已发生问题的复盘。后续工作前应优先参考。

## 终端命令交付前检查

每次把可复制命令发给用户前，agent必须对最终完整命令块逐项复核，不得只检查被调用脚本。
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

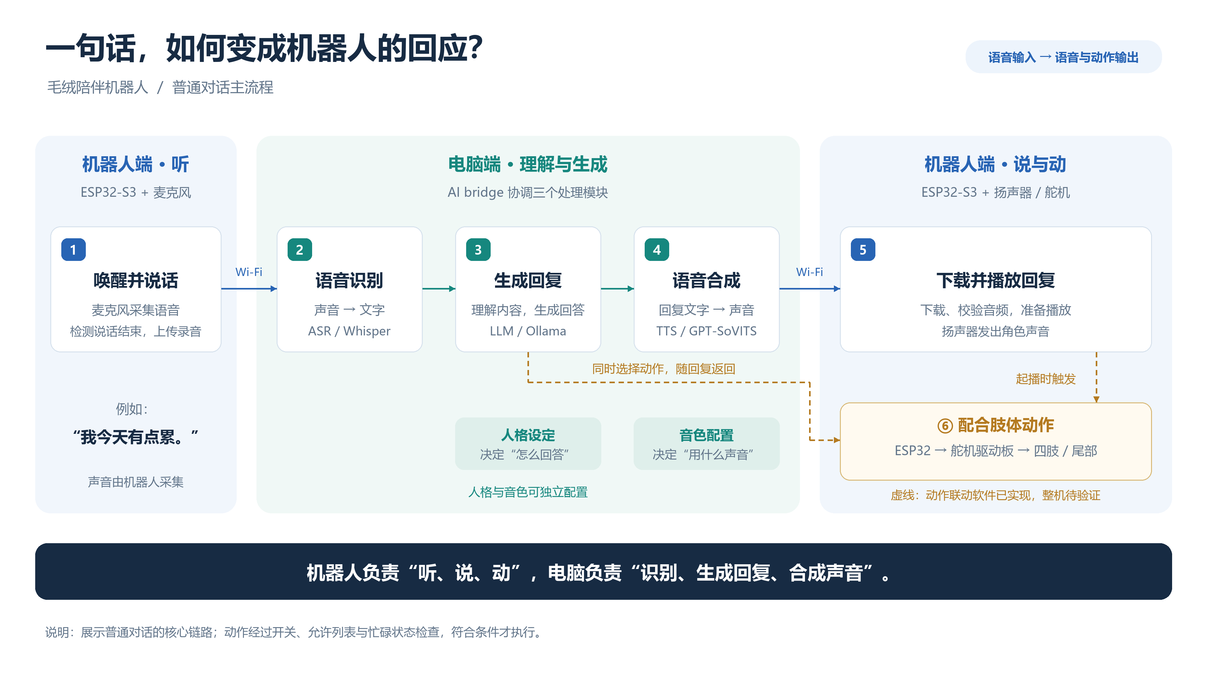
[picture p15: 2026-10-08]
docs/答辩材料/项目交互流程图.png

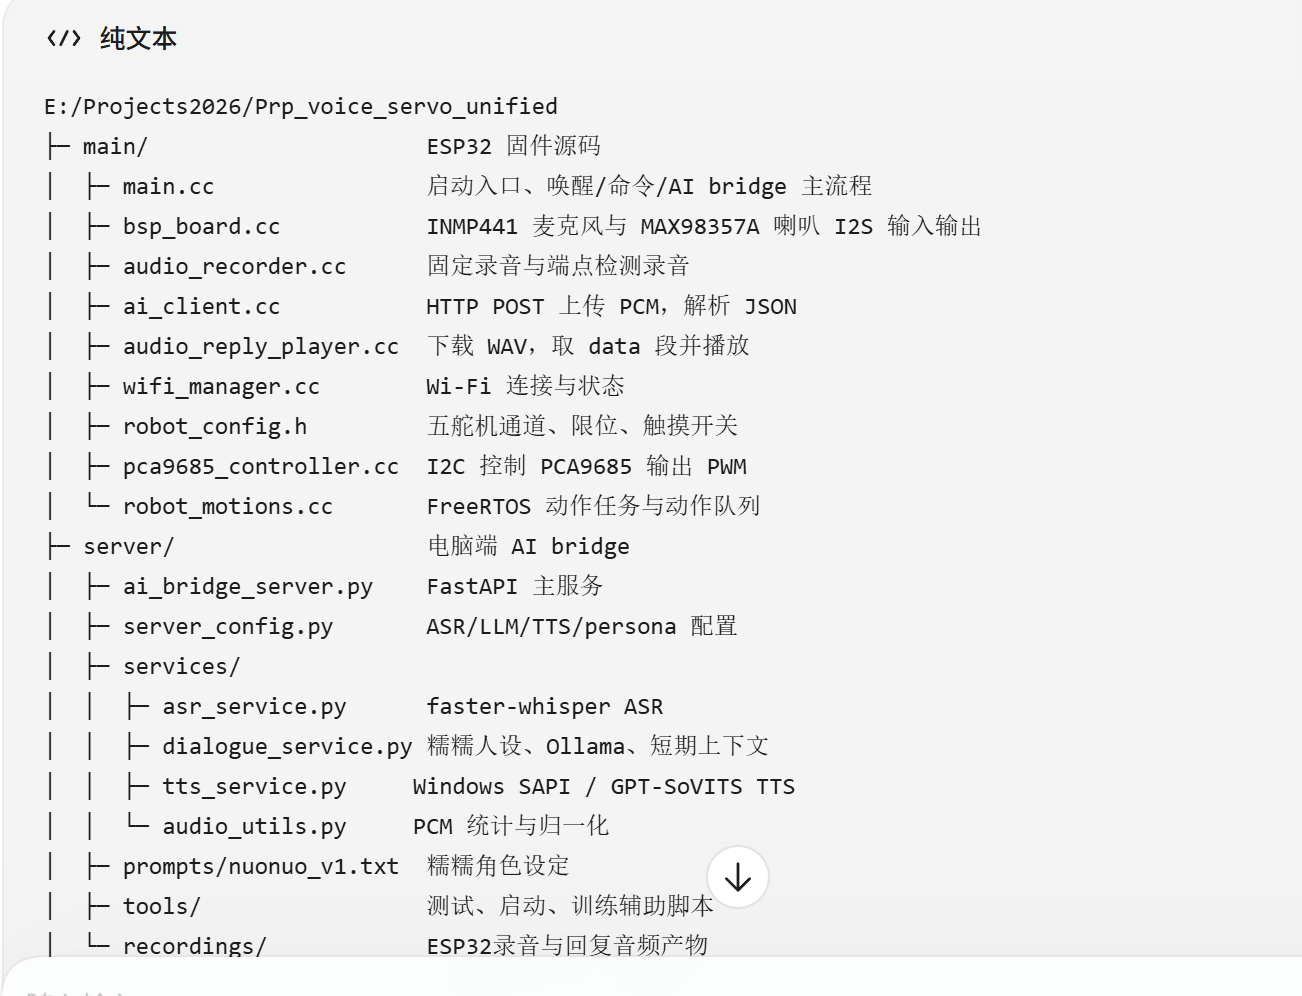
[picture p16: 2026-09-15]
docs/assets/project_structure_map_snapshot_20260915.png

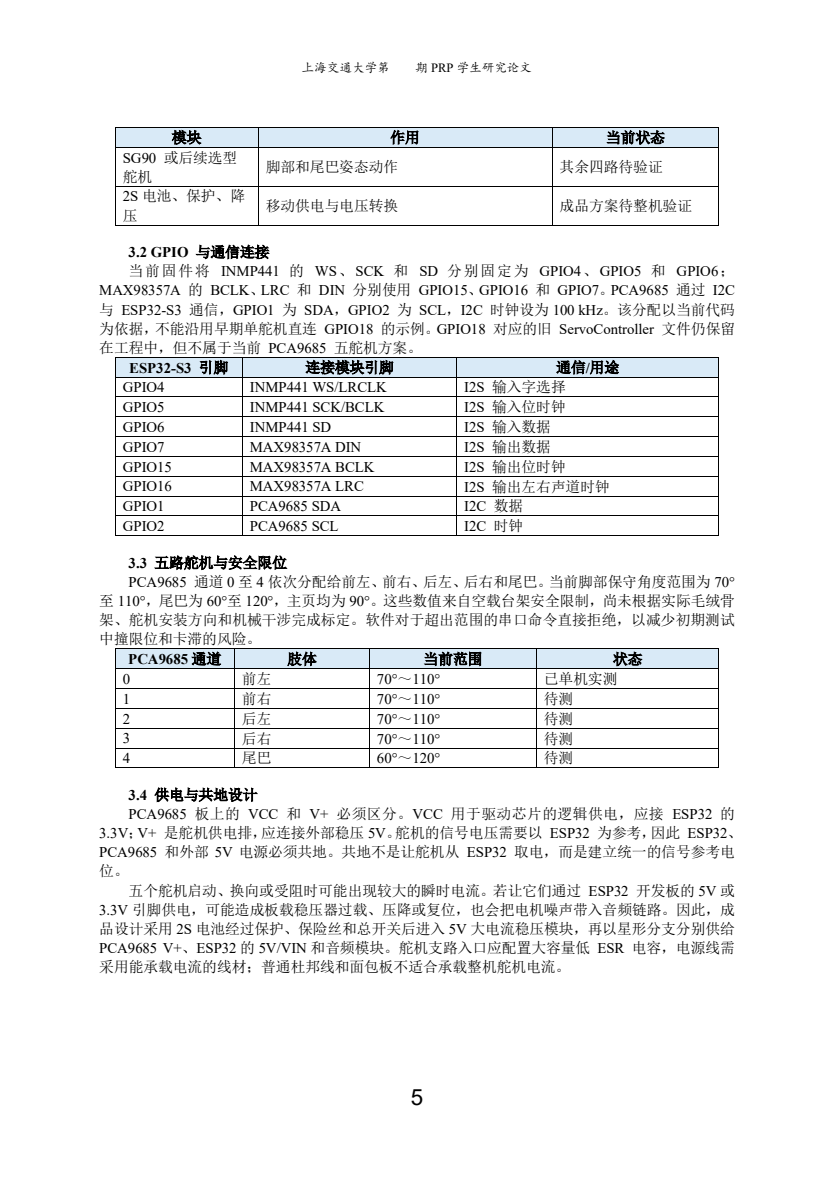
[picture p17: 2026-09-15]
论文初稿/排版检查/page_5.png

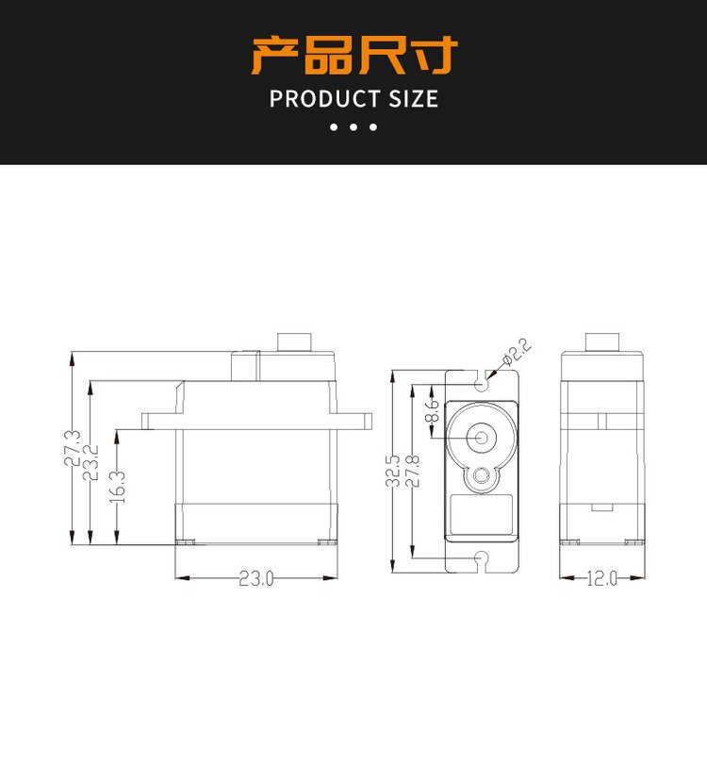
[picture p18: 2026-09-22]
硬件参数/SG90.jpg

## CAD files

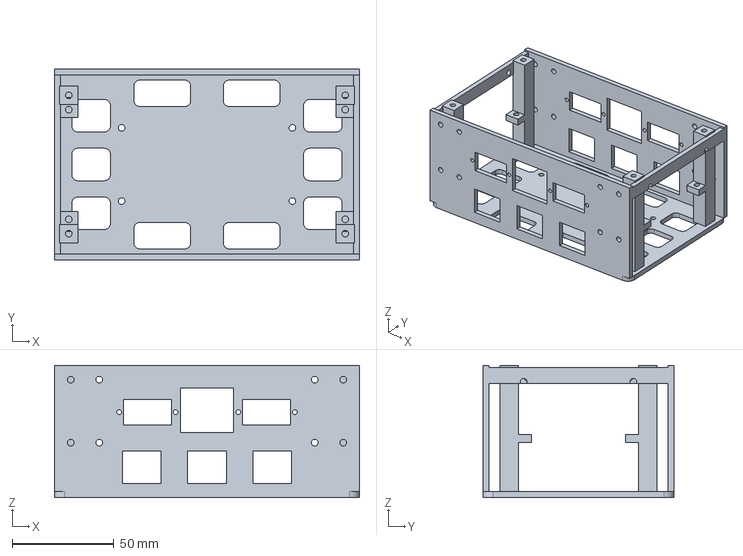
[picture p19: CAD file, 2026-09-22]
mechanical/v0/output/step_parts/01_main_frame.step
150.0 x 94.0 x 65.0 mm

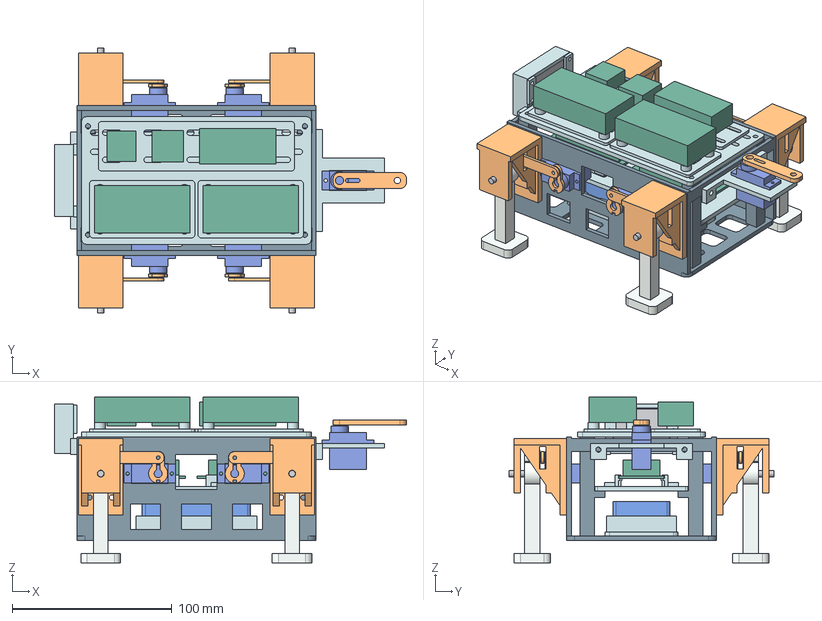
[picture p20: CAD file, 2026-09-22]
mechanical/v0/output/PRP_V0_with_hardware.step
220.7 x 166.0 x 104.0 mm
01_main_frame
02_battery_cradle
03_lower_electronics_deck
04_PCA_edge_rail_-1
04_PCA_edge_rail_1
04_ESP_edge_rail_-1
04_ESP_edge_rail_1
05_upper_power_deck
06_converter_sled_-34
06_converter_sled_34
07_accessory_strip
08_hip_fork_front_R
09_leg_front_R
10_link_front_R
11_horn_adapter_front_R
08_hip_fork_front_L
09_leg_front_L
10_link_front_L
11_horn_adapter_front_L
08_hip_fork_rear_R
09_leg_rear_R
10_link_rear_R
11_horn_adapter_rear_R
08_hip_fork_rear_L
09_leg_rear_L
10_link_rear_L
11_horn_adapter_rear_L
12_tail_servo_mount
13_tail_horn_arm
14_speaker_front_cage
15_speaker_retainer_-1
15_speaker_retainer_1
REF_battery_68x36x18_UNCONFIRMED_SKU
REF_PCA_board_outline
REF_PCA_component_height_ASSUMED
REF_ESP_board_outline
REF_ESP_component_height_ASSUMED
REF_converter_60x30x16_UNCONFIRMED_SKU_-34
REF_converter_60x30x16_UNCONFIRMED_SKU_34
REF_MAX98357_18x19_height_ASSUMED
REF_microphone_RESERVE_20x20x10
REF_power_switch_fuse_BMS_RESERVE_48x22x15
REF_SG90_front_R
REF_metal_bushing_6OD_4ID_10L_front_R
REF_M4_axle_front_R
REF_SG90_front_L
REF_metal_bushing_6OD_4ID_10L_front_L
REF_M4_axle_front_L
REF_SG90_rear_R
REF_metal_bushing_6OD_4ID_10L_rear_R
REF_M4_axle_rear_R
REF_SG90_rear_L
REF_metal_bushing_6OD_4ID_10L_rear_L
REF_M4_axle_rear_L
REF_SG90_tail
REF_speaker_35x25x7p8_allowance

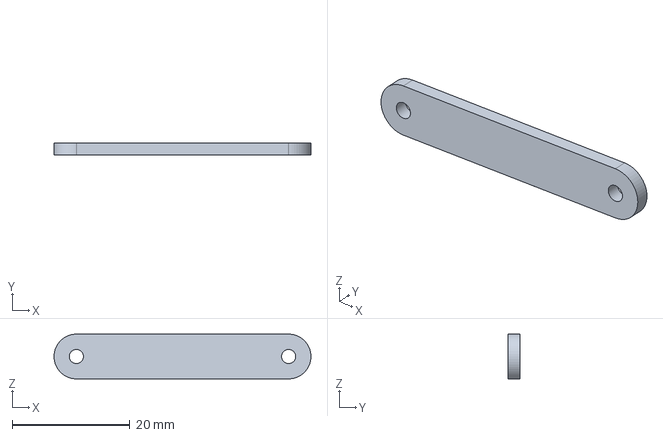
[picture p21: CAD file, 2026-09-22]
mechanical/v0/output/step_parts/10_link_front_L.step
43.6 x 2.00 x 7.60 mm

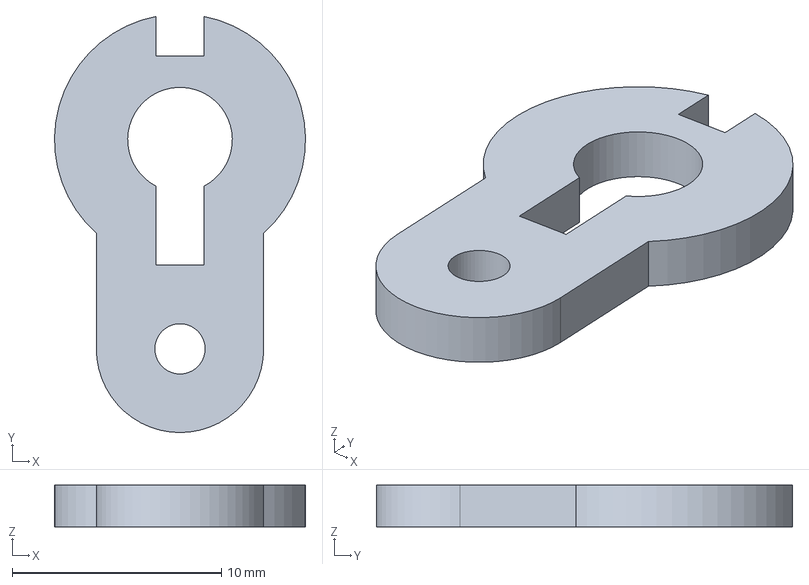
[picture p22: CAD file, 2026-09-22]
mechanical/v0/output/stl_trial/T04_original_horn_adapter.step
12.0 x 19.9 x 2.00 mm

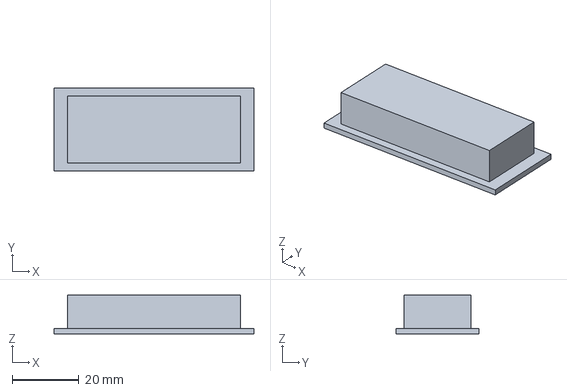
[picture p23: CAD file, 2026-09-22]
mechanical/硬件草模/03_PCA9685_驱动板.step
60.0 x 25.0 x 11.6 mm

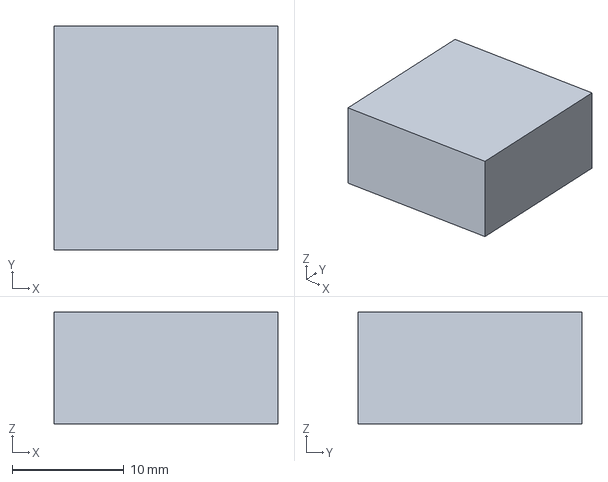
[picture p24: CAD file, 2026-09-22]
mechanical/硬件草模/占位_未定尺寸/08_INMP441_仅20x20x10占位.step
20.0 x 20.0 x 10.0 mm

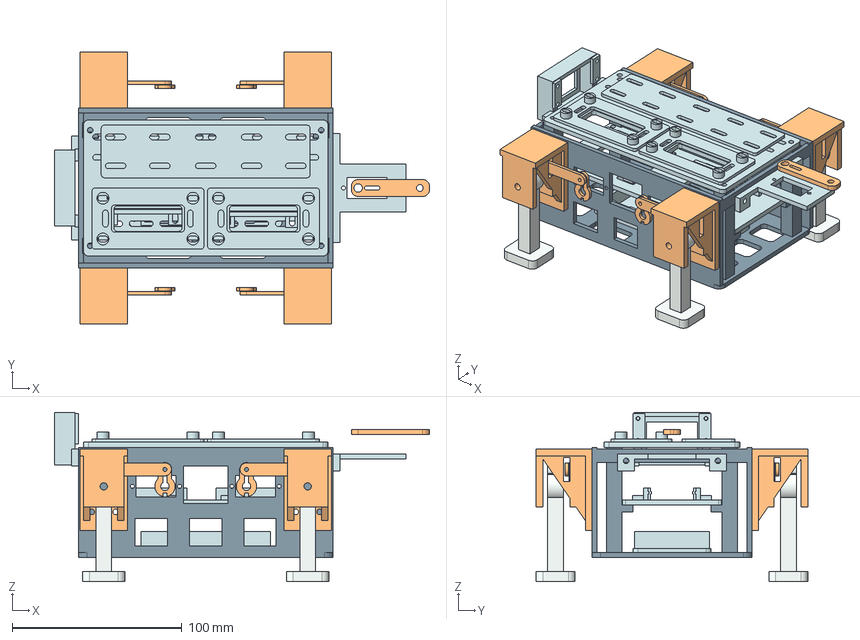
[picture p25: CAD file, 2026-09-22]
mechanical/v0/output/PRP_V0_frame_only.step
220.7 x 160.0 x 99.5 mm
01_main_frame
02_battery_cradle
03_lower_electronics_deck
04_PCA_edge_rail_-1
04_PCA_edge_rail_1
04_ESP_edge_rail_-1
04_ESP_edge_rail_1
05_upper_power_deck
06_converter_sled_-34
06_converter_sled_34
07_accessory_strip
08_hip_fork_front_R
09_leg_front_R
10_link_front_R
11_horn_adapter_front_R
08_hip_fork_front_L
09_leg_front_L
10_link_front_L
11_horn_adapter_front_L
08_hip_fork_rear_R
09_leg_rear_R
10_link_rear_R
11_horn_adapter_rear_R
08_hip_fork_rear_L
09_leg_rear_L
10_link_rear_L
11_horn_adapter_rear_L
12_tail_servo_mount
13_tail_horn_arm
14_speaker_front_cage
15_speaker_retainer_-1
15_speaker_retainer_1

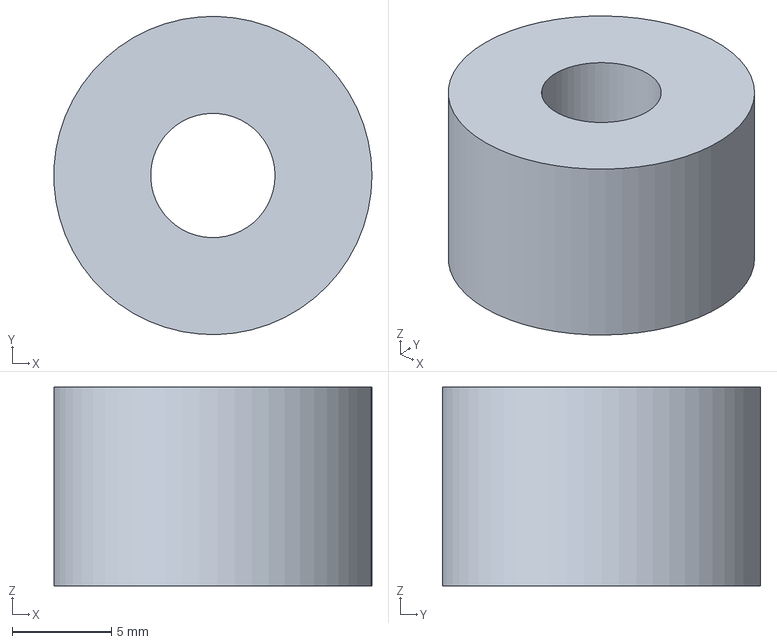
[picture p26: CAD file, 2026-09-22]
mechanical/v0/output/stl_trial/T05_leg_pivot_bushing_fit.step
16.0 x 16.0 x 10.0 mm

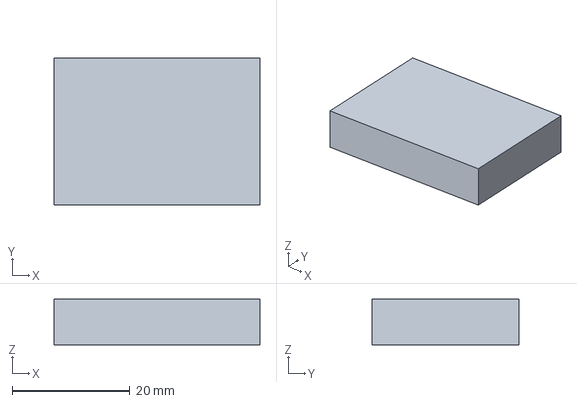
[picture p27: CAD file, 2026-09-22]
mechanical/硬件草模/07_扬声器_35x25_厚度暂定.step
35.0 x 25.0 x 7.80 mm

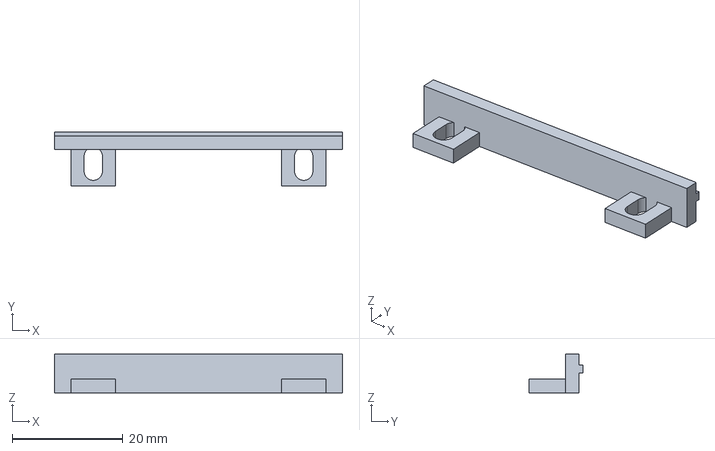
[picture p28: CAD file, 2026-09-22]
mechanical/v0/output/step_parts/04_ESP_edge_rail_-1.step
52.0 x 9.70 x 7.00 mm

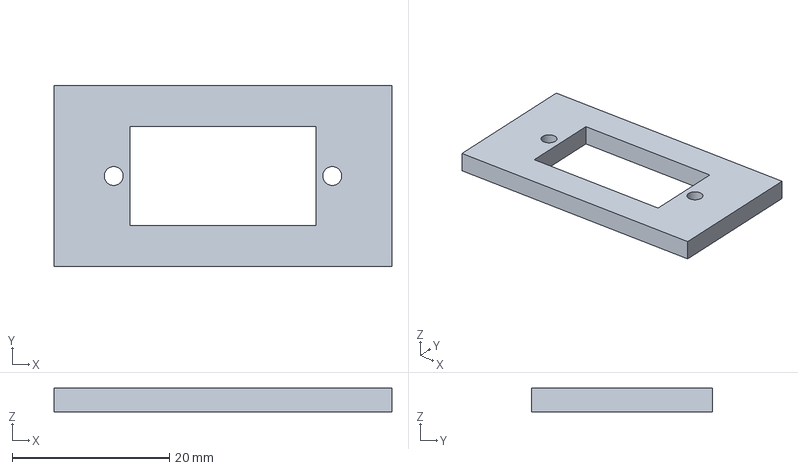
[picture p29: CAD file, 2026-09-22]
mechanical/v0/output/stl_trial/T01_SG90_panel.step
43.0 x 23.0 x 3.00 mm

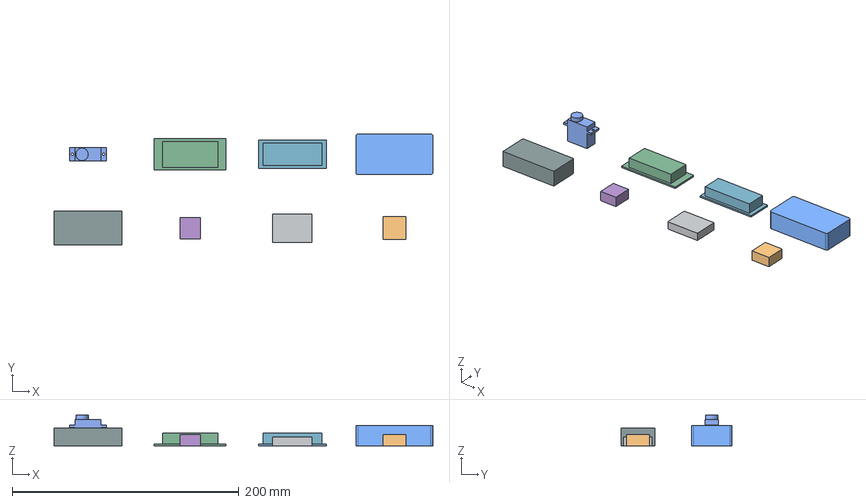
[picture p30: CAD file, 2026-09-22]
mechanical/硬件草模/00_硬件草模总览_非装配布局.step
334.0 x 98.0 x 27.3 mm

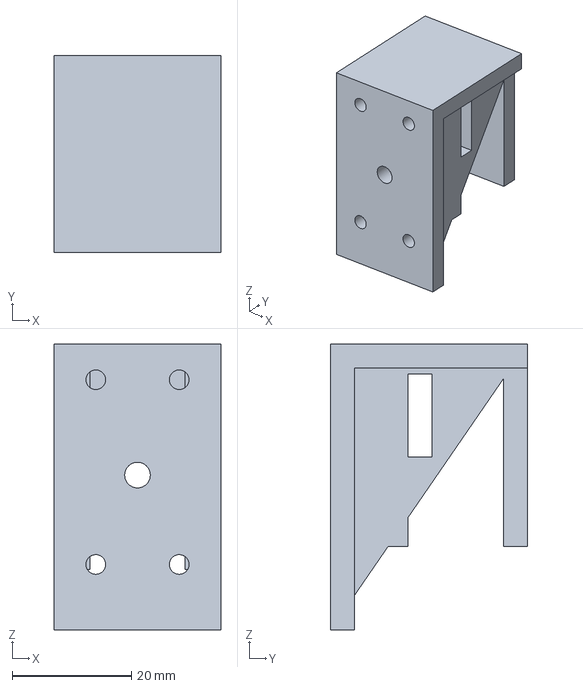
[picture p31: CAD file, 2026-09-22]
mechanical/v0/output/step_parts/08_hip_fork_rear_L.step
28.0 x 33.0 x 48.0 mm

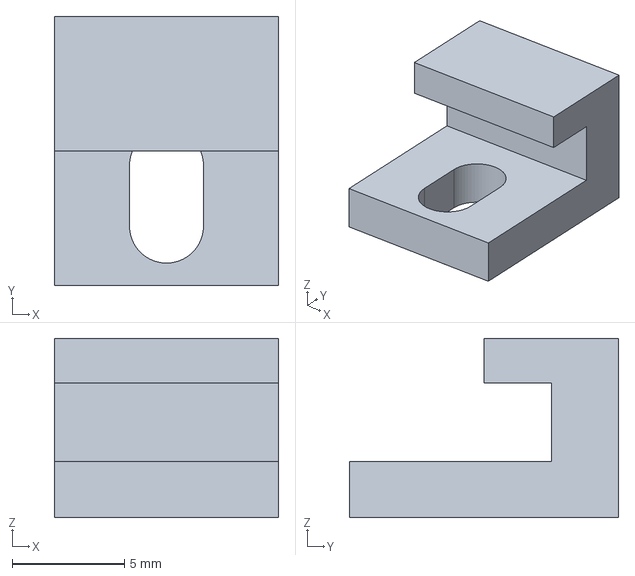
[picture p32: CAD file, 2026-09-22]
mechanical/v0/output/stl_trial/T03_accessory_edge_clip.step
10.0 x 12.0 x 8.00 mm

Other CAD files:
mechanical/v0/output/step_parts/10_link_front_R.step
mechanical/硬件草模/04_电池_68x36x18_型号待核对.step
mechanical/v0/output/step_parts/08_hip_fork_front_L.step
mechanical/v0/output/stl_trial/T02_holes_2p4_3p3_4p3_6p25.step
mechanical/v0/output/PRP_V0_with_hardware.SLDASM
mechanical/v0/output/step_parts/02_battery_cradle.step
mechanical/v0/output/step_parts/03_lower_electronics_deck.step
mechanical/v0/output/step_parts/04_ESP_edge_rail_1.step
mechanical/v0/output/step_parts/04_PCA_edge_rail_-1.step
mechanical/v0/output/step_parts/04_PCA_edge_rail_1.step
mechanical/v0/output/step_parts/05_upper_power_deck.step
mechanical/v0/output/step_parts/06_converter_sled_-34.step
mechanical/v0/output/step_parts/06_converter_sled_34.step
mechanical/v0/output/step_parts/07_accessory_strip.step
mechanical/v0/output/step_parts/08_hip_fork_front_R.step
mechanical/v0/output/step_parts/08_hip_fork_rear_R.step
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

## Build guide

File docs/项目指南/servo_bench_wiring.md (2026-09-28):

# PCA9685 单舵机台架接线与测试

> 2026-09-28：下文0=前左及旧工程烧录命令属于历史台架记录，不适用于当前装机。当前用户接线为左前15、右前11、左后7、右后3、尾0，请使用`servo_channel_setup.md`。首次只测试尾部，不执行全体回中；OE旧常开接法不作为本轮安全方案。用户目前无万用表，外部5V/极性/负载能力尚未验收，不凭照片允许五路带载。

## 1. 本轮测试范围

本轮只验证 `ESP32-S3 -> PCA9685 -> 一只 SG90` 能否正常动作。

- 只连接一只舵机，插在 PCA9685 通道 `0`。
- 暂不连接其余舵机、触摸模块、加热片和震动马达。
- 舵机先卸下舵盘，或确保舵盘周围完全无遮挡。
- ESP32 由电脑 USB 供电；舵机使用另一组稳定的 5V 电源。

## 2. PCA9685 的两套电源

PCA9685 板上的 `VCC` 和 `V+` 不是同一个用途：

- `VCC`：给 PCA9685 控制芯片供电，接 ESP32 的 `3V3`。
- `V+`：给舵机电源排供电，接外部稳压电源的 `+5V`。
- `GND`：ESP32、PCA9685、外部 5V 电源必须共地。

因此，“舵机独立供电”是指外部 5V 接 PCA9685 的 `V+` 舵机电源端，而不是让舵机从 ESP32 开发板取电。本轮单舵机测试建议外部 5V 电源至少能稳定提供 2A；五个 SG90 的正式电源先按持续 5V/5A 级别验证。

## 3. 固定接线表

### 3.1 ESP32-S3 到 PCA9685 控制排针

| ESP32-S3 接口 | PCA9685 接口 | 作用 |
| --- | --- | --- |
| `3V3` | `VCC` | PCA9685 逻辑电源 |
| `GND` | `GND` | 逻辑地和公共参考地 |
| `GPIO1`（板上通常标 `1`） | `SDA` | I2C 数据 |
| `GPIO2`（板上通常标 `2`） | `SCL` | I2C 时钟 |
| `GND` | `OE`（仅当模块引出该脚） | 始终启用输出；无此接口则忽略 |

当前统一工程和旧舵机工程均固定使用 `GPIO1=SDA`、`GPIO2=SCL`，不要改接其他 GPIO。

### 3.2 外部 5V 电源到 PCA9685

| 外部 5V 电源 | PCA9685 接口 |
| --- | --- |
| `+5V` | 螺丝端子或舵机电源端的 `V+` |
| `GND/-` | 螺丝端子或舵机电源端的 `GND` |

再用一根线把外部电源 `GND/-` 与 ESP32 的任意 `GND` 相连。本轮不要把外部电源 `+5V` 接到 ESP32；ESP32 继续由 USB 供电。严禁把 `+5V` 接到 ESP32 的 `3V3`。

### 3.3 SG90 到 PCA9685 通道 0

以 PCA9685 板上印刷的 `GND / V+ / S` 标记为准：

| SG90 导线 | PCA9685 通道 0 |
| --- | --- |
| 棕色或黑色 | `GND`/`-` |
| 红色 | `V+`/`+` |
| 橙色、黄色或白色 | `S`/PWM |

若线色不同，必须先查舵机标签或规格页，不能试插。

## 4. 接线关系图

```text
电脑 USB
   │
   └── ESP32-S3
       ├── 3V3   ───────── PCA9685 VCC
       ├── GND   ───────── PCA9685 GND
       ├── GPIO1 ───────── PCA9685 SDA
       └── GPIO2 ───────── PCA9685 SCL

外部稳压 5V
   ├── +5V ─────────────── PCA9685 V+（舵机电源端）
   └── GND ─────────────── PCA9685 GND，并与 ESP32 GND 共地

PCA9685 通道 0
   ├── GND/- ───────────── SG90 棕/黑线
   ├── V+/+  ───────────── SG90 红线
   └── S     ───────────── SG90 橙/黄/白信号线
```

## 5. 上电前检查

1. 确认外部电源输出约为 5.0V；无法确认电压时不要连接舵机。
2. 确认 `VCC=ESP32 3V3`、`V+=外部5V`，两者没有接反。
3. 确认外部电源负极、PCA9685 GND 和 ESP32 GND 已共地。
4. 确认舵机插头没有反插。
5. 舵盘卸下或处于无负载状态。
6. 本轮只有 PCA9685 通道 0 接舵机。

## 6. 测试步骤

旧舵机工程当前使用 COM7，编译已经通过。确认接线安全后执行：

```powershell
cd E:\Projects2026\Prp
platformio run --target upload --upload-port COM7
platformio device monitor --port COM7 --baud 115200
```

程序启动时会给通道 0、1、2发送 90° 信号。因为本轮只接通道 0，所以只有一个舵机会动作。

在串口监视器中依次输入：

```text
r
s
c
r
```

预期表现：

- `r`：通道 0 回到约 90°；
- `s`：通道 0 缓慢转到约 45°，随后回到 90°；
- `c`：通道 0 缓慢转到约 130°，随后回到 90°；
- 全程不应持续抖动、异常发热、ESP32 重启或明显掉压。

若方向相反不代表故障，后续可调整动作映射。若舵机卡住、尖叫或明显发热，应立即断开外部 5V 舵机电源。

## 7. 通过标准

- PCA9685 初始化成功。
- 通道 0 能响应 `s`、`c`、`r`。
- 连续执行 5 次无卡死或失控。
- ESP32 串口不中断、不重启。
- 舵机和电源线无明显发热。

## 8. 2026-09-08 实测结果

- 用户已按本接线完成单只 SG90 台架测试。
- 已验证舵机能够正常运动，未出现尖叫。
- 该结果证明当前单舵机条件下，ESP32-S3、PCA9685、LM2596 5V 支路、共地和通道 0 控制链路可用。
- 尚未验证五只舵机并发、电源峰值、机械负载、连续 30 次动作和温升，不能把单舵机结果等同于整机通过。

单舵机通过后，统一工程已开始五路配置与非阻塞动作调度改造。

## 9. 舵机接入导致音频失声时的隔离顺序

若扬声器在整套舵机设备接入时无声、断开舵机侧后恢复，不能一次性认定某一只舵机或 PCA9685 损坏。应保持扬声器接线不变，按以下顺序逐步复接，每一步都执行一次 `test audio`：

1. 只接 PCA9685 的 `VCC/GND/SDA/SCL`，不接 `V+` 和舵机。
2. 接入外部稳定 5V 与公共地，仍不接舵机。
3. 只在通道 0 接一只卸载舵盘的 SG90。
4. 单只通过后再逐只增加，禁止直接恢复五只并发测试。

判断方法：

- 第 1 步即失声：检查 PCA9685 控制线误接、3V3/GND 短路或 GPIO 接错。
- 第 2 步失声：重点检查外部 5V 倒灌、公共地连接路径、稳压模块极性与纹波。
- 第 3 步失声：重点检查该舵机反插、堵转、内部故障、5V 电源瞬时电流能力和接线压降。
- 多只后才失声：优先判断总电流不足或地线/电源线压降过大，而不是扬声器损坏。

当前源码 `2026-09-28-servo-map-v1` 在初始化及关闭指令成功后让 PCA9685 全通道 `FULL OFF`；`start machine control` 成功时启用映射内五路，`start servo debug <名称>`成功时只启用选中一路。旧power-safety-v1的广播寄存器处理曾有缺陷，不应使用旧固件验证此保护。新版9月29日编译/离线回归通过、COM7烧录校验成功，运行版本及完整“Hi朋友”已确认；用户明确本次舵机外部电源已断开，未做舵机运动/带载共存验收。关闭PWM不切断V+，不能替代独立5V供电、正确共地和逐项硬件排查。

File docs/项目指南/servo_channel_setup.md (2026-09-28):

# 五路通道配置与尾部单路调试

源码版本：`2026-09-28-servo-map-v1`。当前编译/烧录/实测结果以 `../工作留档/task_progress.md` 为准；写入源码不代表板上已生效。

2026-09-29验证：用户在VS Code运行完整验证脚本，固件编译、既有词库/语音回归及新增舵机主机测试均PASS；随后经明确授权在COM7烧录，写入Hash校验成功并自动复位（31.25s）。串口已确认运行版本、关闭PWM返回成功，用户确认“Hi朋友”完整播放，且明确本次舵机外部电源已断开。该条件下的音频基线通过，尚未验收舵机通电/运动与音频共存。源码未再改变，无需重复验证或烧录。

## 1. 已确认的方向和接线

左右按机器人自身视角。用户确认原俯视照片左侧为前、右侧为尾部；实际接线以本表为准，不再采用旧0～4连续分配。

| 部位 | 串口名称 | PCA9685通道 |
| --- | --- | --- |
| 左前 | fl | 15 |
| 右前 | fr | 11 |
| 左后 | rl | 7 |
| 右后 | rr | 3 |
| 尾部 | tail | 0 |

通道不必连续，分散插接不影响50Hz控制。通道号不是ESP32 GPIO；I2C仍是GPIO1=SDA、GPIO2=SCL，音频引脚不动。

唯一接线配置入口：`main/robot_config.h` 的 `SERVO_CHANNELS`。固定五个部位，初始化、串口名称、限位和动作都使用此映射；动作数组始终按fl/fr/rl/rr/tail排列，不按物理通道号排列。编译时拒绝重复通道及0～15之外的编号。未来更换通道只修改这五项，重新编译并经确认烧录，不用更改动作数组。

`SERVO_LIMITS`记录每只舵机的软件范围和home值，目前仍是未校准的台架初值，所有home=90。改通道不等于完成方向/机械零位校准。

## 2. 上电前的门槛

- 用户照片确认驱动板为PCA9685，背面注明V+最高6V；VCC接ESP32的3V3，舵机V+使用独立稳压5V，共地，USB调试时外部5V不并到ESP32的5V/VIN。
- 当前电源板正面PW008、背面Gold-A029，分别引出VADJ、12V、5.0V、3.3V；照片可辨5.0V区域接线，但不能据此确认另一端的极性、实际电压或额定电流。不能把多路输出电流相加，也不能把不同电压的输出并联。蓝色电池包的电压、保护和电源板输入范围仍需核实。
- 用户目前没有万用表：保持舵机外部电源断开，可先离线编译。实际运动前借用万用表或有可靠读数/限流的测试电源确认5V及极性；五路并发前还需确认单路5V持续/峰值能力及主供电线。不能拿红色电源灯或电容上的耐压值代替测量。
- 主供电不用细杜邦线/面包板承载五路总电流；舵机电流直接经PCA电源端回外部电源，不经ESP32或音频地线回流。软件FULL OFF不切断V+，不能防止电源反接、过压或舵机内部故障。
- 舵盘已装且不便拆卸。第一次使能会直接发送home对应脉冲，SG90不回传当前角度，程序无法保证第一次不跳动。先托住身体、确认舵盘和线束有足够活动空间；若不能保证运动路径无干涉，先卸载连接或调整结构，不强行试0/180度。
- 原语音功能先做基线检查，再逐级复接。此前断开整个舵机子系统后音频恢复，只定位到该子系统，未锁定具体电气原因。OE硬件接法本轮没有修改，不能依赖旧单舵机指南的“始终接地”作为急停保护。

## 3. 只编译，不烧录

在用户可见的VS Code空闲PowerShell运行：

```powershell
powershell -NoProfile -ExecutionPolicy Bypass -File 'E:\Projects2026\Prp_voice_servo_unified\tools\verify_servo_channels.ps1'
```

脚本先执行既有词库/语音日志离线测试、platformio run、音频和trace主机测试，再链接真实PCA9685/RobotMotions源码做主机模拟。覆盖非连续通道、单路掩码、FULL OFF广播和计数高位、错误返回、命令隔离、停止/重新启用时旧动作失效。没有串口访问、真实I2C、真实模型、服务启动或烧录。

`-HostOnly`仅运行舵机主机测试，不能代替固件编译。模拟器在延时边界注入停止/重启，不能替代FreeRTOS实际并发、电气或机械测试。

### 烧录后先验证版本和音频

保持舵机外部电源断开、ESP32通过USB供电；只打开一个监视器。在VS Code空闲PowerShell执行（COM7为9月29日实际枚举的CH343端口，之后更换接口需重新确认）：

```powershell
Set-Location 'E:\Projects2026\Prp_voice_servo_unified'
platformio device monitor -p COM7 -b 115200
```

进入监视器后逐条输入并回车，不是在PowerShell提示符下执行：

```text
status ai bridge
end machine control
test audio
```

预期版本为`2026-09-28-servo-map-v1`。`test audio`仅播放内置欢迎音，不依赖服务器；需要同时核对日志和实际听感。I2S写入成功不等于扬声器已发声。若版本不符、关闭PWM报错或欢迎音不完整，先贴回日志，不进入下一节。不要输入start或servo动作指令；运动仍需确认5V、极性及机械空间。检查结束用Ctrl+C退出监视器，释放COM7。

## 4. 后续批准上板后的尾部步骤

只有完成上一节验证、另行批准烧录、串口确认新版版本号，并满足供电与机械门槛后才能执行。不要把以下命令批量粘贴；一条完成、观察声音与动作后再输入下一条。

1. 支撑机身，输入 `end machine control`，再输入 `test audio`，确认原扬声器仍正常。
2. 输入 `start servo debug tail`。仅通道0发送home=90°（约1500μs）；其余15个通道保持FULL OFF。第一次可能跳到中位，这不是自动校准。
3. 尾部中位无干涉后，逐条输入 `servo tail 92`、`servo tail 90`、`servo tail 88`、`servo tail 90`，每次观察并记录方向。有尖叫、卡住、发热、无声或异常复位立即停止，必要时切断舵机外部电源。
4. 输入 `end servo debug`，关闭全部PWM并取消排队/正在执行的旧动作；再次用 `test audio` 对比。失去PWM保持力可能使身体下落，所以保持托举。

单路模式只允许所选部位home±5°（当前85～95°），拒绝其他部位、`motion`组合动作和直接切到整机模式；语音/AI/触摸动作入口仍关闭。重复start也拒绝，必须先end，避免反复跳中位。`end machine control`同样可以结束单路模式。

若已确认某一路home±5°仍会撞结构，不得使用这些默认值。首先离线修正该路home/限位或卸载机械约束；软件不能推断未测的安装角度。

## 5. 后续校准与动作目标（尚未实现新动作）

用户确认整机约200g，需要真实前进，不只是摆腿；坐下时后脚向身体内侧收。暂按侧面运动平面内“后脚下端朝腹部/前方收”理解，不是左右向中线夹腿，需用单路方向验证确认。

优先尝试保留现有舵盘安装，通过逐路记录home、前后方向和可用行程作软件校准；若安装齿位使站/坐姿超出可用行程，软件不能凭空增加行程，仍需机械调整。不凭照片把原始90°当竖直。

第一阶段只有映射和单路调试，不执行旧happy/shy/curious来代替新步态。之后再配置站姿、后腿内收坐姿、起身、对角步态。四个单关节腿无法独立控制抬脚和前后摆动；对称往复可能原地滑动。200g是用户估计，不是扭矩/重心验收；实际位移需结合支撑、足端摩擦、摆幅和相位落地测量，不能承诺仅靠对角交替必然前进。

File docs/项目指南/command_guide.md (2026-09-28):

# 串口指令指南

本文件用于记录统一工程当前支持的串口输入指令。后续新增、删除或改名指令时，需要同步更新这里。

2026-09-28：源码`servo-map-v1`增加非连续通道与单路模式，是否已编译/烧录见进度记录。首次接入已装配五舵机请先读`servo_channel_setup.md`，不要直接执行全体回90°。未测量外部5V、未检查机械空间时不进入运动测试。

## 使用方式

打开串口监视器：

```powershell
pio device monitor -p COM7 -b 115200
```

在串口监视器中输入完整指令并回车。

## 当前指令

| 指令 | 默认状态 | 作用 |
| --- | --- | --- |
| `start log machine` | 关闭 | 打开机器控制模块日志，包括触摸触发、舵机跳过等信息。 |
| `end log machine` | - | 关闭机器控制模块日志。 |
| `start servo debug <fl\|fr\|rl\|rr\|tail>` | 关闭 | 仅选中一路回home并启用PWM，其余15路保持FULL OFF；首次从tail开始。其他会话须先结束。语音/AI动作仍关闭。 |
| `end servo debug` | - | 关闭全部PWM并取消旧动作；和end machine control一样可以结束单路模式。 |
| `start machine control` | 关闭 | 先在全局断开 PWM 的状态下写入五路主页，再统一启用舵机输出；随后开放串口、语音与 AI 的舵机控制入口。当前台架固件不启用触摸输入。 |
| `end machine control` | - | 关闭机器控制、清空未执行动作，并将 PCA9685 所有通道设为 `FULL OFF`，不再让舵机持续抱紧。 |
| `test audio` | 无需服务器或机器控制 | 播放固件内置欢迎音频，单独检查 ESP32→I2S→MAX98357A→扬声器链路。 |
| `motion reset` | 需先启用机器控制 | 五路舵机缓动回到 90° 主页。 |
| `motion shy` | 需先启用机器控制 | 执行保守幅度的害羞动作，然后复位。 |
| `motion happy` | 需先启用机器控制 | 四脚交替、尾巴摆动，然后复位。 |
| `motion curious` | 需先启用机器控制 | 前脚轻微不对称、尾巴偏转，然后复位。 |
| `servo fl <角度>` | 已启用对应单路或整机 | 左前通道15；单路仅home±5°，整机台架范围70–110°。 |
| `servo fr <角度>` | 已启用对应单路或整机 | 右前通道11；单路仅home±5°，整机台架范围70–110°。 |
| `servo rl <角度>` | 已启用对应单路或整机 | 左后通道7；单路仅home±5°，整机台架范围70–110°。 |
| `servo rr <角度>` | 已启用对应单路或整机 | 右后通道3；单路仅home±5°，整机台架范围70–110°。 |
| `servo tail <角度>` | 已启用对应单路或整机 | 尾部通道0；单路仅home±5°，整机台架范围60–120°。 |

五路使用 PCA9685 通道 `15/11/7/3/0`，依次对应 `fl/fr/rl/rr/tail`；唯一映射配置为`main/robot_config.h::SERVO_CHANNELS`。所有home当前为90°，尚未机械校准。经供电/机械检查和新版烧录确认后，逐条执行尾部示例（不是现在即可批量运行的命令）：

```text
end machine control
test audio
start servo debug tail
servo tail 92
servo tail 90
servo tail 88
servo tail 90
end servo debug
test audio
```

动作命令只向独立 FreeRTOS 动作队列投递请求，串口、网络、录音和播放任务不会等待整个动作完成。当前角度范围是空载台架的保守初值，不代表机械装配后的最终限位；越界命令会被拒绝。

单路模式中的组合动作、其他通道和超出home±5°的请求在动作层也被拒绝。首次使能直接发送home，软件不知道舵机实际位置，可能跳动；先托举并确认无干涉。I2C运动写入失败会停止会话并尝试关闭全部PWM；若关闭也失败，必须人工切断舵机电源，不能把软件停止当作已断电。

## 当前语音口令

| 语音口令 | 当前映射 |
| --- | --- |
| “你好小智” | 唤醒语音模块。 |
| “帮我开灯” | 临时映射为 `actionHappy()`。 |
| “帮我关灯” | 临时映射为 `actionShy()`。 |
| “拜拜” | 退出命令识别状态，回到等待唤醒。 |

## 设计约定

- 串口只处理白名单指令。
- 未识别的串口输入默认静默忽略，避免键盘误输入刷屏。
- 初始化成功后PCA9685全部PWM保持`FULL OFF`。`start machine control`启用映射内五路及整机动作入口；`start servo debug <名称>`只启用单路，不开放触摸/本地命令词/AI动作。两个模式不能直接切换，必须先end；硬件OE/供电保护仍需独立确认。
- 当前 `TOUCH_INPUTS_ENABLED=false`。GPIO8/9/10 尚未接触摸模块时禁止轮询，避免悬空电平反复触发动作；接入真实触摸硬件并完成电平、上下拉和消抖测试后才能启用。
- 机器日志默认关闭，避免未连接触摸和 PCA9685 时产生噪声日志。

## 音频输出自检

新版固件可在串口直接输入：

```text
test audio
```

该指令只播放编译进固件的欢迎音频，不访问 Wi-Fi、AI bridge 或 GPT-SoVITS：

- 能完整播放：ESP32、I2S、功放和扬声器基本正常，应继续检查服务器回复 WAV 的下载日志。
- 日志出现 `Local audio self-test failed`：根据同一行的 ESP-IDF 错误排查 I2S 驱动状态。
- 日志显示 `I2S write succeeded` 但完全无声：软件已经把数据交给 I2S，优先检查 MAX98357A 的 VIN/GND、DIN/BCLK/LRC、扬声器接线和供电能力。

当前输出引脚固定为 `DIN→GPIO7`、`BCLK→GPIO15`、`LRC→GPIO16`，ESP32 与 MAX98357A 必须共地。测试时先执行 `end machine control`，必要时再断开舵机外部 5V，排除大电流负载导致的电压跌落。

## AI Bridge Commands And Setup

Start the computer test server:

```powershell
cd E:\Projects2026\Prp_voice_servo_unified\server
python -m pip install -r requirements.txt
python -m uvicorn ai_bridge_server:app --host 0.0.0.0 --port 8000
```

Check the server from the computer:

```powershell
curl http://127.0.0.1:8000/health
```

Configure ESP32 Wi-Fi and server URL before uploading:

```text
E:\Projects2026\Prp_voice_servo_unified\main\network_config.h
```

Use `ipconfig` to find the computer IPv4 address, then set `AI_SERVER_URL` like:

```cpp
#define AI_SERVER_URL "http://192.168.1.23:8000/voice/interact"
```

`platformio run` only compiles. `platformio run -t upload` flashes the board and should be done only after confirming that overwriting the current firmware is intended.

## AI Bridge 调试指令

| 指令 | 作用 |
| --- | --- |
| `status ai bridge` | 打印当前固件版本、AI bridge 开关、Wi-Fi 状态、AI bridge 是否可用、电脑服务器地址。 |
| `retry wifi` | 重新尝试连接 Wi-Fi，并更新 AI bridge 可用状态。 |

如果串口里看不到 `Booting PRP voice-servo AI bridge`，说明当前板子上运行的不是这次新增 AI bridge 的固件，或者还没有成功上传。

## 大模型回复调试

当前服务端默认优先调用本地 Ollama：

```text
LLM_BACKEND = "ollama"
OLLAMA_MODEL = "qwen2.5:3b"
OLLAMA_TIMEOUT_SECONDS = 90
OLLAMA_KEEP_ALIVE = "10m"
```

配置文件：

```text
E:\Projects2026\Prp_voice_servo_unified\server\server_config.py
```

如果 Ollama 未安装、未启动或模型未拉取，服务端会自动回退到规则回复，`llm_status` 会显示 `fallback_ollama_error`。

常见问题：

- `ollama` 命令提示未识别：通常是刚安装后当前 PowerShell 没刷新 PATH。重新打开终端，或直接运行 `C:\Users\ASUS\AppData\Local\Programs\Ollama\ollama.exe`。
- `WinError 10048` / `address already in use`：说明 `8000` 端口已有服务器在运行。先测试 `curl http://127.0.0.1:8000/health`；如果需要加载新代码，结束旧的 `python -m uvicorn` 进程后再启动。
- `llm_status` 为 `fallback_ollama_error` 且 detail 里是 `Read timed out`：多半是模型首次加载超过超时窗口。当前默认已放宽到 90 秒，也可临时设置 `$env:PRP_OLLAMA_TIMEOUT_SECONDS='120'`。

测试文本回复接口：

```powershell
curl "http://127.0.0.1:8000/debug/dialogue?text=我今天压力好大"
```

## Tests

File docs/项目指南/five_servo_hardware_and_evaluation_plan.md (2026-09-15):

# 五舵机硬件集成与语音量化评估计划

## 1. 文档目的

本文用于规划毛绒治愈机器人下一阶段工作，覆盖：

- 四个脚部舵机和一个尾巴舵机的机械与扭矩验证；
- 舵机控制与语音功能合并到同一块 ESP32-S3；
- 电源、驱动板和线束的小型化；
- 为论文汇报建立可重复、可对比的语音与整机指标。

本文中的器件能力和目标值属于设计估计，必须经过实物测量后才能作为论文实验结果。

## 2. 已核实的项目基线

### 2.1 旧舵机工程

- 当前路径：`E:\Projects2026\Prp`。
- 计划名称：`E:\Projects2026\Prp_servo_control`。
- 技术栈：PlatformIO、Arduino、ESP32-S3。
- 控制方式：PCA9685，经 GPIO1/GPIO2 的 I2C 控制。
- 已实现三路舵机：头部、左侧、右侧；并非现在需要的四脚加尾巴五路结构。
- 已实现限位、缓动、串口动作命令和三路触摸输入。

旧工程只作为可追溯参考，后续正式开发继续放在统一工程：

`E:\Projects2026\Prp_voice_servo_unified`

### 2.2 当前统一工程

- 已把旧工程的 PCA9685、三路动作和触摸模块移植为 ESP-IDF 实现。
- 语音链路已实现唤醒、录音、ASR、Ollama 回复、GPT-SoVITS 合成和音频回放。
- AI 服务已经返回统一的 `motion` 意图，但动作层仍是旧三路舵机语义。
- 机器控制默认关闭，适合在未接舵机时单独测试语音。
- 当前动作函数使用 `vTaskDelay()` 串行缓动；扩展到五路后会阻塞调用任务，不适合语音播放与动作并发。

### 2.3 已确认硬件清单

材料清单中的相关模块为：

| 模块 | 已记录型号 | 实际职责 | 当前判断 |
| --- | --- | --- | --- |
| 主控 | ESP32-S3 开发板 | 语音、Wi-Fi、逻辑与动作调度 | 保留一块，统一控制 |
| 舵机驱动 | PCA9685 16 通道板 | 生成舵机 PWM 信号 | 原型阶段保留，最终可评估去除或做小板 |
| 舵机 | SG90 9g | 原计划头、耳、身体动作 | 现改为四脚加尾巴，共五个 |
| 电池 | 2S 7.4V 2200mAh | 移动供电 | 需确认是否自带保护板 |
| 充电 | TP5100 | 给 2S 电池充电 | 不能代替保护板或稳压器 |
| 降压 | LM2596 模块 | 7.4V 降至 5V/3.3V | 功能必须保留，可换更紧凑方案 |
| 音频 | I2S 麦克风、MAX98357A、4Ω 3W 喇叭 | 语音输入输出 | 已由统一 ESP32-S3 使用 |

## 3. 舵机扭矩与尺寸判断

### 3.1 不能只按“9g 或 5g”选择

舵机重量不是扭矩指标。需要先确定脚部是：

1. **装饰摆动**：脚不承受机器人重量，只带动较轻的毛绒和骨架；
2. **姿态调整**：脚会推动身体改变坐姿或重心；
3. **承重/移动**：脚需要支撑或移动整机。

只有第一种情况适合优先尝试 2g、3.7g 或 5g 微型舵机。后两种情况不能为了缩小体积而直接降低扭矩。

### 3.2 估算公式

舵机轴所需静态扭矩可按下式初估：

```text
静态扭矩（kgf·cm）≈ 负载质量（kg）× 重心到转轴距离（cm）
选型扭矩 ≥ 静态扭矩 × 动态系数 ÷ 传动效率
```

- 缓慢摆动可先取动态系数 `1.5–2.0`。
- 快速启停、毛绒挤压或可能卡住时取 `2.0–3.0`。
- 简单连杆的传动效率可暂按 `0.6–0.8` 估算。
- 正常动作所需扭矩最好不超过舵机堵转扭矩的约 `40%–50%`，避免发热、抖动和寿命快速下降。

示例：若整机 1kg，由四脚平均承重，有效力臂 3cm，动态系数 2，传动效率 0.7，则单腿建议扭矩约为：

```text
(1kg ÷ 4) × 3cm × 2 ÷ 0.7 ≈ 2.1kgf·cm
```

这时普通 SG90 的余量已经不大，更小舵机通常不合适。若单只脚只是带动约 30g 的软质部件、重心距轴 4cm，则设计扭矩约为 `0.4kgf·cm`，才有机会使用更小舵机。

### 3.3 当前建议范围

| 部位/工况 | 建议起始扭矩等级 | 初步选择方向 |
| --- | ---: | --- |
| 不承重的短脚摆动 | ≥0.8–1.2kgf·cm | 3.7g–5g 微型舵机可试 |
| 带动较厚毛绒或调整坐姿 | ≥1.5–2.5kgf·cm | SG90 级或更可靠的同尺寸舵机 |
| 承重或推动整机 | ≥2.5–4kgf·cm，需实测 | 不建议缩小；优先结构减载或金属齿轮舵机 |
| 轻质尾巴摆动 | ≥0.3–0.8kgf·cm | 2g–3.7g 舵机可试 |

不同厂商标注差异很大，上表不能替代样品实测。

### 3.4 最小扭矩实测

在购买五个新舵机前，先制作一个脚部和尾巴样件：

1. 在最不利姿态下，用弹簧秤或电子秤测量使部件刚开始运动的力。
2. 记录施力点到转轴的垂直距离。
3. 用“力（kgf）× 距离（cm）”计算静态扭矩。
4. 乘以至少 2 倍安全系数，并考虑毛绒挤压后的附加阻力。
5. 用一只现有 SG90 做低速限位测试，同时测启动、运动和堵转趋势电流。

需要记录：整机质量、单肢质量、力臂、测得力、计算扭矩、动作角度、动作时间、峰值电流、是否发热或卡滞。

## 4. 单 ESP32-S3 合并控制方案

### 4.1 可行性结论

单块 ESP32-S3 同时处理语音和五路舵机是可行的。CPU 和 PWM 通道数不是当前主要瓶颈，主要问题是：

- 舵机电源峰值导致 ESP32 欠压重启；
- 舵机和长线产生的电磁噪声污染麦克风；
- 阻塞式动作代码妨碍录音、网络传输或语音播放；
- 五个舵机同时启动造成机械冲击和瞬时大电流。

### 4.2 PWM 驱动两阶段策略

**原型阶段：保留 PCA9685。**

- 只占两根 I2C 信号线，便于快速扩展到五路。
- PWM 输出不依赖语音任务调度，便于先验证动作与机械结构。
- 缺点是模块尺寸偏大，并增加一块板和连接器。

**紧凑版：评估 ESP32-S3 直接输出五路 LEDC PWM。**

- 可去掉 PCA9685 模块，但仍必须保留独立舵机电源母线。
- 需要完成 GPIO 冲突审计、五路并发抖动测试以及语音播放期间的稳定性测试。
- 若直驱稳定性或布线不理想，最终方案可改为一块小型定制载板，把 PCA9685、电源分配和插座集成在一起，而不是使用成品大模块。

### 4.3 软件结构调整

五路通道建议统一命名为：

```text
front_left, front_right, rear_left, rear_right, tail
```

后续代码按以下边界调整：

- `RobotIntent`：描述开心、安慰、好奇、休息等高层意图；
- `MotionController`：把意图展开为五路关键帧；
- `ServoDriver`：只负责角度限制和 PWM 输出；
- 独立 FreeRTOS 动作任务：通过队列接收动作，按时间片更新五路舵机；
- 语音、网络回调只投递意图，不直接执行长时间 `vTaskDelay()`。

这样可以让语音播放与动作同步进行，并可记录“回复开始播放”和“动作开始”的时间差。

## 5. 供电与布线优化

### 5.1 电源原则

- 不允许五个舵机从 ESP32 开发板的 5V/3.3V 引脚取电。
- 成品状态下 ESP32 不依赖 USB 供电：2S 电池经过 5V 稳压后，5V 母线分别连接舵机支路和 ESP32 开发板的 `5V/VIN` 输入；ESP32 再由板载稳压器产生 3.3V，供麦克风和 PCA9685 的 `VCC` 使用。
- USB 只用于烧录和调试。若开发板没有确认具备 USB 5V 与外部 5V 的电源隔离，调试时应断开外部 `5V/VIN`，或使用断开 5V 线、只保留数据线的 USB 线，避免两路 5V 互相倒灌。
- 2S 锂电池、TP5100、保护板和降压模块的职责必须分别确认。
- 舵机使用独立的 5V 大电流支路，ESP32/音频使用较干净的逻辑电源支路，所有模块共地。
- 以 SG90 级舵机估算时，应按多个舵机同时启动的峰值留余量；第一版电源建议从持续 5V/5A 级别开始验证，而不是相信小模块的瞬时宣传值。
- 在舵机电源入口附近增加大容量低 ESR 电容，起始可试 `1000–2200µF`，每个模块附近保留去耦；最终数值以示波器或欠压日志验证。
- 加入总电源开关、保险丝或自恢复保险丝，并确保电池具备匹配 2S 的保护功能。

成品单电池供电拓扑：

```text
2S 7.4V 电池（满电 8.4V）
        │
   2S 保护板/BMS
        │
    保险丝＋总开关
        │
  5V/6A～8A 稳压模块
        │
        ├── 舵机支路：PCA9685 V+ → 五只舵机
        │              舵机入口并联 2200～4700µF 电容
        │
        ├── 主控支路：ESP32-S3 的 5V/VIN
        │              ESP32 板载 3.3V → INMP441、PCA9685 VCC
        │
        └── 音频支路：MAX98357A VIN（按实际模块允许电压接 5V）

所有支路 GND 在电源分配点共地。
```

这里的“一个电源”指一块电池。锂电池电压会变化，因此仍必须经过稳压；所谓 5V 充电宝内部同样包含稳压电路。若只使用一个 5V 稳压模块，应采用星形分支和滤波，避免舵机电流经过 ESP32 或麦克风的地线。

### 5.2 减小体积的优先顺序

1. 先确定五个舵机所需扭矩和实际同时动作数量。
2. 用一个满足峰值电流的紧凑同步降压/UBEC 替代体积较大的 LM2596 成品板。
3. 把舵机电源分配、公共地、滤波电容和插座集中到洞洞板或定制 PCB。
4. 验证 ESP32 直出五路 PWM，成功后再移除 PCA9685；或者把 PCA9685 芯片直接集成到小型载板。
5. 最后才根据机械实测替换更小舵机。

### 5.3 线束结构

- 面包板只用于低电流逻辑验证，不承载舵机电流。
- 使用一块中心配电板，五个舵机采用三针防呆插座；电源采用星形分配，避免串接。
- 舵机电源线优先使用比杜邦线更粗的线材；信号线与麦克风数据线分开走线。
- 电池、降压、舵机母线尽量靠近机器人重心；麦克风远离舵机、降压电感和大电流线。
- 线束按前左、前右、后左、后右、尾巴编号，并预留应力释放和可拆卸接口。
- 最终使用可拆卸电子内胆，避免清洗毛绒外套时拉扯线束。

## 6. 论文可用的量化指标

### 6.1 语音识别

| 指标 | 计算或记录方式 | 用途 |
| --- | --- | --- |
| 字错误率 CER | 编辑距离 ÷ 参考文本字数 | 衡量普通话识别准确度 |
| 整句正确率 | 完全正确句数 ÷ 总句数 | 比 CER 更容易用于汇报 |
| 唤醒成功率 | 正确唤醒次数 ÷ 有效唤醒尝试 | 衡量 WakeNet |
| 误唤醒率 | 无唤醒词时每小时误触发次数 | 衡量日常可用性 |
| 端点完整率 | 未漏开头、未截尾的录音数 ÷ 总录音数 | 衡量录音状态机 |

建议固定 30–50 条测试句，在安静/普通室内噪声、20cm/50cm 两种距离下重复测试。比较同一批录音在优化前后的结果。

### 6.2 响应速度

至少记录以下时间点，并计算中位数 P50 和较差情况 P90：

- 说话结束到录音结束；
- 上传耗时；
- ASR 耗时；
- LLM 耗时；
- TTS 耗时；
- 音频下载耗时；
- 说话结束到开始播放的端到端延迟；
- 动作开始与语音开始的同步误差。

服务端已有 ASR、LLM、TTS 和总耗时，后续需增加统一 `request_id`，并补齐 ESP32 侧录音、上传、下载、播放和动作时间戳。

### 6.3 回复亲和力与质量

使用盲测问卷比较“规则回复/原始提示词”和“优化后回复”，每项 1–5 分：

- 温暖感；
- 自然度；
- 与用户情绪的相关性；
- 是否简洁、适合语音播放；
- 是否让人感到压力或说教；
- 整体偏好。

同时记录客观辅助指标：平均回复字数、超长回复率、安全规则通过率、LLM 回退率。论文中报告均值、标准差和偏好胜率，不把少量主观反馈表述成临床效果。

### 6.4 TTS 与整机可靠性

- 合成语音可懂度：用 ASR 反识别生成语音并计算 CER。
- 主观自然度 MOS：1–5 分。
- 音色相似度：盲听 1–5 分；后续条件允许时再增加说话人嵌入余弦相似度。
- TTS 实时率 RTF：合成耗时 ÷ 音频时长。
- 端到端成功率：一次交互完整经历识别、回复、合成、下载、播放和动作的比例。
- 后端回退率、HTTP 失败率、重启/欠压次数。
- 动作重复成功率、最大电流、动作噪声和连续运行温升。

### 6.5 建议的阶段目标

以下仅作为工程目标，需用基线测试后再调整：

- 安静环境整句识别正确率 ≥90%。
- 端点完整率 ≥95%。
- 端到端成功率 ≥90%。
- 报告 P50/P90 延迟，并使优化后 P50 至少下降 20%。
- 回复温暖感和自然度平均分 ≥4/5，或相对基线盲测偏好率 ≥65%。
- 连续 30 次动作无撞限位、无 ESP32 欠压重启。

## 7. 后续工作流程与验收门槛

### 阶段 0：机械和电源事实确认

1. 称量整机、单只脚、尾巴及连杆。
2. 测量每个转轴到负载重心的距离。
3. 明确四脚是否承重、是否需要移动整机。
4. 拍摄并记录电池标签、TP5100、LM2596、PCA9685 和 SG90 实物正反面。
5. 使用单只 SG90 完成力和电流测试。

验收：形成真实尺寸、质量、力臂、扭矩和电流表；之后才决定微型舵机型号。

### 阶段 1：五舵机独立台架

1. 暂时保留 PCA9685 和独立 5V 舵机电源。
2. 把统一工程扩展为五路命名、限位和复位配置。
3. 增加单通道测试、全体复位和分组动作串口命令。
4. 先空载，再单肢加载，最后测试最多两个舵机同时动作。

验收：每路连续动作 30 次无撞限位；全系统无掉电、无异常复位；记录峰值电流。

### 阶段 2：非阻塞动作与语音同步

1. 把串行 `vTaskDelay()` 动作改为独立任务和关键帧调度。
2. 语音/触摸/服务端统一输出 `RobotIntent`。
3. 记录动作与音频开始时间，调整同步偏移。

验收：播放语音期间动作流畅，录音和网络任务不被动作长时间阻塞。

### 阶段 3：小型化与线束定型

1. 对比“直连 ESP32 五路 PWM”和“小型 PCA9685 载板”。
2. 选择满足实测峰值电流的紧凑电源方案。
3. 制作中心配电/转接板和短线束，停止用面包板承载舵机电流。
4. 在毛绒与填充物装配状态下复测噪声、卡滞、温升和麦克风干扰。

验收：形成可装入外壳的尺寸图、接线图、BOM 和实物照片。

### 阶段 4：建立语音基线与逐项优化

1. 固定测试语料、距离和噪声条件。
2. 给服务端和 ESP32 增加结构化 JSONL/CSV 调试记录。
3. 先采集基线，再逐项调整端点检测、ASR 模型、提示词和 TTS。
4. 每次只改变一个主要变量，保留配置版本号。

验收：能够给出基线与改进后的 CER、P50/P90 延迟、成功率和主观评分对比。

### 阶段 5：整机演示与论文证据

1. 完成语音回复与五舵机动作的情绪映射。
2. 做连续交互、弱网、噪声和低电量测试。
3. 保存日志、测试表、照片和视频编号。
4. 将“已实现”“实测结果”“设计目标”严格分开表述。

## 8. 当前最小下一步

2026-09-08 状态：现有 SG90、PCA9685 和独立 5V 的单舵机台架已实测正常运动且无尖叫；统一工程已实现五路配置、保守限位、安全串口命令和独立动作队列，并通过编译，尚未烧录和五路实测。

下一步：

1. 保持仅连接通道 0，烧录统一固件后先用 `servo fl 80/100/90` 验证新动作层。
2. 再依次把同一只舵机换接通道 1–4，逐路验证命名、方向和安全限位。
3. 确认单路无误后，最多先接两只舵机测试并发动作和 ESP32 是否欠压重启。
4. 五路装机前测量机械限位和负载，修正每路主页、方向和最小/最大角度。
5. 台架数据确认后，再决定是否采购更小舵机及是否移除 PCA9685。

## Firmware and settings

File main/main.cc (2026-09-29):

/**
 * @file main.cc
 * @brief ESP32-S3 智能语音助手 - 舵机控制主程序
 *
 * 本程序实现了完整的智能语音助手功能，包括：
 * 1. 语音唤醒检测 - 支持"你好小智"等多种唤醒词
 * 2. 命令词识别 - 支持"帮我开灯"、"帮我关灯"、"拜拜"等语音指令
 * 3. 音频反馈播放 - 通过MAX98357A功放播放确认音频
 * 4. 舵机控制 - 根据语音指令控制舵机旋转
 *
 * 硬件配置：
 * - ESP32-S3-DevKitC-1开发板（需要PSRAM版本）
 * - INMP441数字麦克风（音频输入）
 *   连接方式：VDD->3.3V, GND->GND, SD->GPIO6, WS->GPIO4, SCK->GPIO5
 * - MAX98357A数字功放（音频输出）
 *   连接方式：DIN->GPIO7, BCLK->GPIO15, LRC->GPIO16, VIN->3.3V, GND->GND
 * - PCA9685 五路舵机驱动（GPIO1=SDA, GPIO2=SCL）
 *   舵机使用独立稳压 5V，ESP32、PCA9685 和舵机电源必须共地
 *
 * 音频参数：
 * - 采样率：16kHz
 * - 声道：单声道(Mono)
 * - 位深度：16位
 *
 * 使用的AI模型：
 * - 唤醒词检测：WakeNet9 "你好小智"模型
 * - 命令词识别：MultiNet7中文命令词识别模型
 */

extern "C"
{
#include <stdio.h>
#include <stdlib.h>
#include <string.h>
#include "freertos/FreeRTOS.h"
#include "freertos/task.h"
#include "esp_wn_iface.h"           // 唤醒词检测接口
#include "esp_wn_models.h"          // 唤醒词模型管理
#include "esp_mn_iface.h"           // 命令词识别接口
#include "esp_mn_models.h"          // 命令词模型管理
#include "esp_mn_speech_commands.h" // 命令词配置
#include "esp_process_sdkconfig.h"  // sdkconfig处理函数
#include "model_path.h"             // 模型路径定义
#include "bsp_board.h"              // 板级支持包，INMP441麦克风驱动
#include "esp_log.h"                // ESP日志系统
#include "esp_timer.h"
#include "mock_voices/welcome.h"    // 欢迎音频数据文件
#include "mock_voices/light_on.h"   // 开灯音频数据文件
#include "mock_voices/light_off.h"  // 关灯音频数据文件
#include "mock_voices/byebye.h"     // 再见音频数据文件
#include "driver/gpio.h"            // GPIO驱动
#include "driver/ledc.h"            // LEDC PWM驱动，用于舵机控制
}

#include "ai_client.h"
#include "audio_reply_player.h"
#include "audio_recorder.h"
#include "phrase_background.h"
#include "network_config.h"
#include "servo_controller.h" // 舵机控制器类
#include "robot_motions.h"
#include "touch_inputs.h"
#include "wifi_manager.h"

static const char *TAG = "主控";
static const char *FIRMWARE_NAME = "PRP voice-servo AI bridge";
static const char *FIRMWARE_VERSION = "2026-09-29-phrase-motion-v1";

// 系统状态定义
typedef enum
{
    STATE_WAITING_WAKEUP = 0,  // 等待唤醒词
    STATE_WAITING_COMMAND = 1, // 等待命令词
} system_state_t;

// 命令词ID定义（对应commands_cn.txt中的ID）
#define COMMAND_TURN_OFF_LIGHT 308 // "帮我关灯"
#define COMMAND_TURN_ON_LIGHT 309  // "帮我开灯"
#define COMMAND_BYE_BYE 314        // "拜拜"

// 命令词配置结构体
typedef struct
{
    int command_id;
    const char *pinyin;
    const char *description;
} command_config_t;

// 自定义命令词列表
static const command_config_t custom_commands[] = {
    {COMMAND_TURN_ON_LIGHT, "bang wo kai deng", "帮我开灯"},
    {COMMAND_TURN_OFF_LIGHT, "bang wo guan deng", "帮我关灯"},
    {COMMAND_BYE_BYE, "bai bai", "拜拜"},
};

#define CUSTOM_COMMANDS_COUNT (sizeof(custom_commands) / sizeof(custom_commands[0]))

// 全局变量
static system_state_t current_state = STATE_WAITING_WAKEUP;
static esp_mn_iface_t *multinet = NULL;
static model_iface_data_t *mn_model_data = NULL;
static TickType_t command_timeout_start = 0;
static const TickType_t COMMAND_TIMEOUT_MS = 5000; // 5秒超时

// 舵机控制器实例
static ServoController servo_controller;
static RobotMotions robot_motions;
static TouchInputs touch_inputs;
static bool machine_log_enabled = false;
static bool machine_control_enabled = false;
// Serial-only single-output session. Never opens voice/AI/touch motion gates.
static bool single_servo_debug_enabled = false;
static bool ai_bridge_ready = false;

typedef enum
{
    AI_INTERACTION_OK = 0,
    AI_INTERACTION_SKIPPED,
    AI_INTERACTION_NO_SPEECH,
    AI_INTERACTION_FAILED,
} ai_interaction_result_t;

static void trim_line(char *text)
{
    size_t len = strlen(text);
    while (len > 0 && (text[len - 1] == '\n' || text[len - 1] == '\r' || text[len - 1] == ' '))
    {
        text[len - 1] = '\0';
        len--;
    }
}

static const ServoLimit *get_servo_limit(uint8_t channel)
{
    for (size_t i = 0; i < SERVO_LIMIT_COUNT; ++i)
    {
        if (SERVO_LIMITS[i].channel == channel)
        {
            return &SERVO_LIMITS[i];
        }
    }
    return nullptr;
}

static bool servo_channel_from_name(const char *name, uint8_t *channel)
{
    if (strcmp(name, "fl") == 0)
    {
        *channel = SERVO_FRONT_LEFT;
    }
    else if (strcmp(name, "fr") == 0)
    {
        *channel = SERVO_FRONT_RIGHT;
    }
    else if (strcmp(name, "rl") == 0)
    {
        *channel = SERVO_REAR_LEFT;
    }
    else if (strcmp(name, "rr") == 0)
    {
        *channel = SERVO_REAR_RIGHT;
    }
    else if (strcmp(name, "tail") == 0)
    {
        *channel = SERVO_TAIL;
    }
    else
    {
        return false;
    }
    return true;
}

static void handle_serial_servo_command(const char *line)
{
    char name[8] = {};
    int angle = 0;
    char extra = '\0';
    if (sscanf(line, "servo %7s %d %c", name, &angle, &extra) != 2)
    {
        ESP_LOGW(TAG, "Usage: servo <fl|fr|rl|rr|tail> <angle>");
        return;
    }

    uint8_t channel = 0;
    if (!servo_channel_from_name(name, &channel))
    {
        ESP_LOGW(TAG, "Unknown servo '%s'; use fl, fr, rl, rr, or tail", name);
        return;
    }

    const ServoLimit *limit = get_servo_limit(channel);
    if (limit == nullptr || angle < limit->min_angle || angle > limit->max_angle)
    {
        ESP_LOGW(TAG, "Angle rejected for %s; safe range is %d-%d degrees",
                 name,
                 limit != nullptr ? limit->min_angle : 0,
                 limit != nullptr ? limit->max_angle : 0);
        return;
    }

    if (!robot_motions.requestServoAngle(channel, angle))
    {
        ESP_LOGW(TAG, "Servo command rejected: check mode/channel, debug home +/-5 degrees, PCA9685 and queue");
        return;
    }
    ESP_LOGI(TAG, "Servo command queued: %s channel=%u angle=%d", name, channel, angle);
}

static void serial_command_task(void *arg)
{
    (void)arg;
    char line[96];

    ESP_LOGI(TAG, "Serial commands ready: test audio, machine control/log, motion <name>, servo <name> <angle>, AI bridge status/retry");

    while (1)
    {
        if (fgets(line, sizeof(line), stdin) == NULL)
        {
            vTaskDelay(pdMS_TO_TICKS(50));
            continue;
        }

        trim_line(line);

        if (strcmp(line, "start log machine") == 0)
        {
            machine_log_enabled = true;
            robot_motions.setLogEnabled(true);
            ESP_LOGI(TAG, "Machine module logs enabled");
        }
        else if (strcmp(line, "end log machine") == 0)
        {
            machine_log_enabled = false;
            robot_motions.setLogEnabled(false);
            ESP_LOGI(TAG, "Machine module logs disabled");
        }
        else if (strcmp(line, "start machine control") == 0)
        {
            if (single_servo_debug_enabled)
            {
                ESP_LOGW(TAG, "单路调试中禁止启用整机，请先输入 end servo debug");
            }
            else if (machine_control_enabled)
            {
                ESP_LOGI(TAG, "Machine control is already enabled");
            }
            else
            {
                esp_err_t output_ret = robot_motions.enableOutputsAtHome();
                if (output_ret == ESP_OK)
                {
                    machine_control_enabled = true;
                    ESP_LOGI(TAG, "Machine control enabled at home pose (touch inputs compiled %s)",
                             TOUCH_INPUTS_ENABLED ? "on" : "off");
                }
                else
                {
                    ESP_LOGE(TAG, "Machine control enable failed; verify PWM off or disconnect servo power: %s",
                             esp_err_to_name(output_ret));
                }
            }
        }
        else if (strncmp(line, "start servo debug ", 18) == 0 || strcmp(line, "start servo debug") == 0)
        {
            char name[8] = {};
            char extra = '\0';
            uint8_t channel = 0;
            if (sscanf(line, "start servo debug %7s %c", name, &extra) != 1 ||
                !servo_channel_from_name(name, &channel))
            {
                ESP_LOGW(TAG, "Usage: start servo debug <fl|fr|rl|rr|tail>");
            }
            else if (machine_control_enabled || single_servo_debug_enabled)
            {
                ESP_LOGW(TAG, "请先停止当前舵机会话：end machine control 或 end servo debug");
            }
            else
            {
                esp_err_t output_ret = robot_motions.enableSingleServoAtHome(channel);
                if (output_ret == ESP_OK)
                {
                    single_servo_debug_enabled = true;
                    const ServoLimit *limit = get_servo_limit(channel);
                    ESP_LOGI(TAG, "单路调试 %s → 通道%u，中位%d°，只接受%d～%d°；语音动作保持关闭",
                             name, channel, limit->home_angle,
                             limit->home_angle - SERVO_DEBUG_SPAN_DEGREES,
                             limit->home_angle + SERVO_DEBUG_SPAN_DEGREES);
                }
                else
                {
                    ESP_LOGE(TAG, "单路启用失败：%s；确认PWM关闭，必要时断开舵机电源", esp_err_to_name(output_ret));
                }
            }
        }
        else if (strcmp(line, "end machine control") == 0 || strcmp(line, "end servo debug") == 0)
        {
            machine_control_enabled = false;
            single_servo_debug_enabled = false;
            esp_err_t output_ret = robot_motions.disableOutputs();
            if (output_ret == ESP_OK)
            {
                ESP_LOGI(TAG, "Machine control disabled; all servo PWM outputs are off");
            }
            else
            {
                ESP_LOGE(TAG, "Machine control disabled but PWM shutdown failed: %s",
                         esp_err_to_name(output_ret));
            }
        }
        else if (strcmp(line, "test audio") == 0)
        {
            ESP_LOGI(TAG, "Local audio self-test started: built-in welcome prompt, no server involved");
            esp_err_t audio_ret = bsp_play_audio(welcome, welcome_len);
            if (audio_ret == ESP_OK)
            {
                ESP_LOGI(TAG, "Local audio self-test completed: I2S write succeeded");
            }
            else
            {
                ESP_LOGE(TAG, "Local audio self-test failed: %s", esp_err_to_name(audio_ret));
            }
        }
        else if (strcmp(line, "motion reset") == 0 || strcmp(line, "motion shy") == 0 ||
                 strcmp(line, "motion happy") == 0 || strcmp(line, "motion curious") == 0)
        {
            if (!machine_control_enabled)
            {
                ESP_LOGW(TAG, "Machine control is disabled; run 'start machine control' first");
            }
            else if (strcmp(line, "motion reset") == 0)
            {
                robot_motions.actionReset();
            }
            else if (strcmp(line, "motion shy") == 0)
            {
                robot_motions.actionShy();
            }
            else if (strcmp(line, "motion happy") == 0)
            {
                robot_motions.actionHappy();
            }
            else
            {
                robot_motions.actionCurious();
            }
        }
        else if (strncmp(line, "servo ", 6) == 0)
        {
            if (!machine_control_enabled && !single_servo_debug_enabled)
            {
                ESP_LOGW(TAG, "舵机未启用；首次测试请用 start servo debug tail，仅开启尾部");
            }
            else
            {
                handle_serial_servo_command(line);
            }
        }
        else if (strcmp(line, "status ai bridge") == 0)
        {
            ESP_LOGI(TAG, "Firmware: %s (%s)", FIRMWARE_NAME, FIRMWARE_VERSION);
            ESP_LOGI(TAG, "AI bridge enabled: %d", AI_BRIDGE_ENABLED);
            ESP_LOGI(TAG, "Wi-Fi status: %s", wifi_manager_status_text());
            ESP_LOGI(TAG, "AI bridge ready: %d", ai_bridge_ready);
            ESP_LOGI(TAG, "AI server URL: %s", AI_SERVER_URL);
        }
        else if (strcmp(line, "retry wifi") == 0)
        {
            esp_err_t wifi_ret = wifi_manager_start();
            ai_bridge_ready = (wifi_ret == ESP_OK);
            ESP_LOGI(TAG, "Wi-Fi retry result: %s, AI bridge ready: %d",
                     esp_err_to_name(wifi_ret), ai_bridge_ready);
        }
    }
}

static void handle_touch_event()
{
    if (!TOUCH_INPUTS_ENABLED || !machine_control_enabled)
    {
        return;
    }

    switch (touch_inputs.poll())
    {
    case TouchEvent::Touch1:
        if (machine_log_enabled)
        {
            ESP_LOGI(TAG, "Touch 1 detected -> shy action");
        }
        robot_motions.actionShy();
        break;
    case TouchEvent::Touch2:
        if (machine_log_enabled)
        {
            ESP_LOGI(TAG, "Touch 2 detected -> happy action");
        }
        robot_motions.actionHappy();
        break;
    case TouchEvent::Touch3:
        if (machine_log_enabled)
        {
            ESP_LOGI(TAG, "Touch 3 detected -> curious action");
        }
        robot_motions.actionCurious();
        break;
    case TouchEvent::None:
    default:
        break;
    }
}

static void dispatch_ai_motion(void *context)
{
    const char *motion = static_cast<const char *>(context);
    if (motion == NULL || motion[0] == '\0' || strcmp(motion, "none") == 0)
    {
        return;
    }

    if (!machine_control_enabled)
    {
        if (machine_log_enabled)
        {
            ESP_LOGI(TAG, "AI motion skipped because machine control is disabled: %s", motion);
        }
        return;
    }

    if (!robot_motions.tryStartVoiceMotion(motion) && machine_log_enabled)
    {
        ESP_LOGI(TAG, "AI动作未启动（禁用/忙碌/无效），语音继续：%s", motion);
    }
}
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
extern "C" void app_main(void)
{
    ESP_LOGI(TAG, "启动固件：%s (%s)", FIRMWARE_NAME, FIRMWARE_VERSION);

    // ========== 第一步：初始化舵机 ==========
    esp_err_t motion_ret = robot_motions.init();
    if (motion_ret != ESP_OK)
    {
        ESP_LOGW(TAG, "Robot motion init failed, voice-only test mode continues: %s", esp_err_to_name(motion_ret));
    }

    if (TOUCH_INPUTS_ENABLED)
    {
        esp_err_t touch_ret = touch_inputs.init();
        if (touch_ret != ESP_OK)
        {
            ESP_LOGW(TAG, "Touch input init failed, voice-only test mode continues: %s", esp_err_to_name(touch_ret));
        }
    }
    else
    {
        ESP_LOGI(TAG, "Touch inputs disabled for servo bench testing");
    }

    xTaskCreate(serial_command_task, "serial_command_task", 4096, NULL, 5, NULL);

    if (AI_BRIDGE_ENABLED)
    {
        esp_err_t wifi_ret = wifi_manager_start();
        ai_bridge_ready = (wifi_ret == ESP_OK);
        if (ai_bridge_ready)
        {
            ESP_LOGI(TAG, "AI bridge networking is ready");
        }
        else
        {
            ESP_LOGW(TAG, "AI bridge networking is not ready, local command mode remains available");
        }
    }

    // ========== 第二步：初始化INMP441麦克风硬件 ==========
    esp_err_t ret = bsp_board_init(16000, 1, 16); // 16kHz, 单声道, 16位
    if (ret != ESP_OK)
    {
        ESP_LOGE(TAG, "INMP441麦克风初始化失败: %s", esp_err_to_name(ret));
        ESP_LOGE(TAG, "请检查硬件连接: VDD->3.3V, GND->GND, SD->GPIO6, WS->GPIO4, SCK->GPIO5");
        return;
    }

    // ========== 第三步：初始化音频播放功能 ==========
    ret = bsp_audio_init(16000, 1, 16); // 16kHz, 单声道, 16位
    if (ret != ESP_OK)
    {
        ESP_LOGE(TAG, "音频播放初始化失败: %s", esp_err_to_name(ret));
        ESP_LOGE(TAG, "请检查MAX98357A硬件连接: DIN->GPIO7, BCLK->GPIO15, LRC->GPIO16");
        return;
    }

    // ========== 第四步：初始化语音识别模型 ==========
    ESP_LOGI(TAG, "加载本地唤醒词和命令词模型...");

    // 检查内存状态
    size_t free_heap = heap_caps_get_free_size(MALLOC_CAP_8BIT);

    if (free_heap < 100 * 1024)
    {
        ESP_LOGE(TAG, "可用内存不足，需要至少100KB");
        return;
    }

    // 从模型目录加载所有可用的语音识别模型

    // 临时添加错误处理和重试机制
    srmodel_list_t *models = NULL;
    int retry_count = 0;
    const int max_retries = 3;

    while (models == NULL && retry_count < max_retries)
    {
        // 在每次重试前等待一下
        if (retry_count > 0)
        {
            vTaskDelay(pdMS_TO_TICKS(1000));
        }

        models = esp_srmodel_init("model");

        if (models == NULL)
        {
            ESP_LOGW(TAG, "模型加载失败，准备重试...");
            retry_count++;
        }
    }
    if (models == NULL)
    {
        ESP_LOGE(TAG, "语音识别模型初始化失败");
        ESP_LOGE(TAG, "请检查模型文件是否正确烧录到Flash分区");
        return;
    }

    // 自动选择sdkconfig中配置的唤醒词模型（如果配置了多个模型则选择第一个）
    char *model_name = esp_srmodel_filter(models, ESP_WN_PREFIX, NULL);
    if (model_name == NULL)
    {
        ESP_LOGE(TAG, "未找到任何唤醒词模型！");
        ESP_LOGE(TAG, "请确保已正确配置并烧录唤醒词模型文件");
        ESP_LOGE(TAG, "可通过 'idf.py menuconfig' 配置唤醒词模型");
        return;
    }

    // 获取唤醒词检测接口
    esp_wn_iface_t *wakenet = (esp_wn_iface_t *)esp_wn_handle_from_name(model_name);
    if (wakenet == NULL)
    {
        ESP_LOGE(TAG, "获取唤醒词接口失败，模型: %s", model_name);
        return;
    }

    // 创建唤醒词模型数据实例
    // DET_MODE_90: 检测模式，90%置信度阈值，平衡准确率和误触发率
    model_iface_data_t *model_data = wakenet->create(model_name, DET_MODE_90);
    if (model_data == NULL)
    {
        ESP_LOGE(TAG, "创建唤醒词模型数据失败");
        return;
    }

    // ========== 第五步：初始化命令词识别模型 ==========

    // 获取中文命令词识别模型（MultiNet7）
    char *mn_name = esp_srmodel_filter(models, ESP_MN_PREFIX, ESP_MN_CHINESE);
    if (mn_name == NULL)
    {
        ESP_LOGE(TAG, "未找到中文命令词识别模型！");
        ESP_LOGE(TAG, "请确保已正确配置并烧录MultiNet7中文模型");
        return;
    }

    // 获取命令词识别接口
    multinet = esp_mn_handle_from_name(mn_name);
    if (multinet == NULL)
    {
        ESP_LOGE(TAG, "获取命令词识别接口失败，模型: %s", mn_name);
        return;
    }

    // 创建命令词模型数据实例
    mn_model_data = multinet->create(mn_name, 6000);
    if (mn_model_data == NULL)
    {
        ESP_LOGE(TAG, "创建命令词模型数据失败");
        return;
    }

    // 配置自定义命令词
    esp_err_t cmd_config_ret = configure_custom_commands(multinet, mn_model_data);
    if (cmd_config_ret != ESP_OK)
    {
        ESP_LOGE(TAG, "命令词配置失败");
        return;
    }

    // ========== 第六步：准备音频缓冲区 ==========
    // 获取模型要求的音频数据块大小（样本数 × 每样本字节数）
    int audio_chunksize = wakenet->get_samp_chunksize(model_data) * sizeof(int16_t);

    // 分配音频数据缓冲区内存
    int16_t *buffer = (int16_t *)malloc(audio_chunksize);
    if (buffer == NULL)
    {
        ESP_LOGE(TAG, "音频缓冲区内存分配失败，需要 %d 字节", audio_chunksize);
        ESP_LOGE(TAG, "请检查系统可用内存");
        return;
    }

    // 显示系统配置信息
    ESP_LOGI(TAG, "本地模型就绪：唤醒=%s | 命令=%s | 音频=16kHz/单声道/16bit", model_name, mn_name);

    // ========== 第七步：主循环 - 实时音频采集与语音识别 ==========
    ESP_LOGI(TAG, "系统启动完成，等待唤醒词 '你好小智'...");

    while (1)
    {
        // 从INMP441麦克风获取一帧音频数据
        // false参数表示获取处理后的音频数据（非原始通道数据）
        esp_err_t ret = bsp_get_feed_data(false, buffer, audio_chunksize);
        if (ret != ESP_OK)
        {
            ESP_LOGE(TAG, "麦克风音频数据获取失败: %s", esp_err_to_name(ret));
            ESP_LOGE(TAG, "请检查INMP441硬件连接");
            vTaskDelay(pdMS_TO_TICKS(10)); // 等待10ms后重试
            continue;
        }

        handle_touch_event();

        if (current_state == STATE_WAITING_WAKEUP)
        {
            // 第一阶段：唤醒词检测
            wakenet_state_t wn_state = wakenet->detect(model_data, buffer);

            if (wn_state == WAKENET_DETECTED)
            {
                ESP_LOGI(TAG, "已唤醒，播放欢迎音");

                // 播放欢迎音频
                esp_err_t audio_ret = bsp_play_audio(welcome, welcome_len);
                if (audio_ret != ESP_OK)
                {
                    ESP_LOGE(TAG, "音频播放失败: %s", esp_err_to_name(audio_ret));
                }

                ai_interaction_result_t ai_result = run_ai_bridge_conversation(audio_chunksize);
                if (ai_result == AI_INTERACTION_OK)
                {
                    current_state = STATE_WAITING_WAKEUP;
                    ESP_LOGI(TAG, "本次会话结束，等待唤醒词“你好小智”");
                    continue;
                }
                if (ai_result == AI_INTERACTION_NO_SPEECH)
                {
                    current_state = STATE_WAITING_WAKEUP;
                    ESP_LOGI(TAG, "未检测到开口，等待唤醒词“你好小智”");
                    continue;
                }
                ESP_LOGW(TAG, "AI交互不可用，回到本地命令模式");

                // 切换到命令词识别状态
                current_state = STATE_WAITING_COMMAND;
                command_timeout_start = xTaskGetTickCount();
                multinet->clean(mn_model_data); // 清理命令词识别缓冲区
                ESP_LOGI(TAG, "本地命令：帮我开灯 / 帮我关灯 / 拜拜（5秒无指令退出）");
            }
        }
        else if (current_state == STATE_WAITING_COMMAND)
        {
            // 第二阶段：命令词识别
            esp_mn_state_t mn_state = multinet->detect(mn_model_data, buffer);

            if (mn_state == ESP_MN_STATE_DETECTED)
            {
                // 获取识别结果
                esp_mn_results_t *mn_result = multinet->get_results(mn_model_data);
                if (mn_result->num > 0)
                {
                    int command_id = mn_result->command_id[0];
                    float prob = mn_result->prob[0];

                    const char *cmd_desc = get_command_description(command_id);
                    ESP_LOGI(TAG, "本地命令：%s | 置信度=%.2f | 机器控制=%s", cmd_desc, prob,
                             machine_control_enabled ? "开启" : "关闭");

                    // 处理具体命令
                    if (command_id == COMMAND_TURN_ON_LIGHT)
                    {
                        if (machine_control_enabled)
                        {
                            robot_motions.actionHappy();
                        }

                        // 播放开灯确认音频
                        esp_err_t audio_ret = bsp_play_audio(light_on, light_on_len);
                        if (audio_ret != ESP_OK)
                        {
                            ESP_LOGE(TAG, "命令确认音播放失败：%s", esp_err_to_name(audio_ret));
                        }
                    }
                    else if (command_id == COMMAND_TURN_OFF_LIGHT)
                    {
                        if (machine_control_enabled)
                        {
                            robot_motions.actionShy();
                        }
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

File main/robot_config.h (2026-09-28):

#pragma once

#include <stddef.h>
#include <stdint.h>

#include "driver/gpio.h"
#include "driver/i2c.h"

static constexpr i2c_port_t ROBOT_I2C_PORT = I2C_NUM_0;
static constexpr gpio_num_t ROBOT_I2C_SDA_PIN = GPIO_NUM_1;
static constexpr gpio_num_t ROBOT_I2C_SCL_PIN = GPIO_NUM_2;
static constexpr uint32_t ROBOT_I2C_FREQ_HZ = 100000;

// GPIO4/5/6 are reserved by INMP441 in the voice module.
static constexpr gpio_num_t TOUCH_1_PIN = GPIO_NUM_8;
static constexpr gpio_num_t TOUCH_2_PIN = GPIO_NUM_9;
static constexpr gpio_num_t TOUCH_3_PIN = GPIO_NUM_10;
// Keep disabled until the three touch inputs are physically connected and
// their active levels/debounce behavior have been verified.
static constexpr bool TOUCH_INPUTS_ENABLED = false;

// 舵机接线唯一配置入口：填 PCA9685 通道号 0~15，不是 ESP32 GPIO。
// 初始化、串口部位名称和动作均使用此映射；改接线只修改这里并重新编译/烧录。
struct ServoChannelMap {
    int front_left;
    int front_right;
    int rear_left;
    int rear_right;
    int tail;
};
static constexpr ServoChannelMap SERVO_CHANNELS = {
    15, // 左前 fl
    11, // 右前 fr
    7,  // 左后 rl
    3,  // 右后 rr
    0,  // 尾部 tail
};

constexpr bool servoChannelsValid(const ServoChannelMap &map) {
    const int channels[] = {map.front_left, map.front_right, map.rear_left, map.rear_right, map.tail};
    for (size_t i = 0; i < 5; ++i) {
        if (channels[i] < 0 || channels[i] > 15) return false;
        for (size_t j = 0; j < i; ++j) {
            if (channels[i] == channels[j]) return false;
        }
    }
    return true;
}
static_assert(servoChannelsValid(SERVO_CHANNELS), "Servo channels must be unique PCA9685 outputs 0..15");
static constexpr uint8_t SERVO_FRONT_LEFT = SERVO_CHANNELS.front_left;
static constexpr uint8_t SERVO_FRONT_RIGHT = SERVO_CHANNELS.front_right;
static constexpr uint8_t SERVO_REAR_LEFT = SERVO_CHANNELS.rear_left;
static constexpr uint8_t SERVO_REAR_RIGHT = SERVO_CHANNELS.rear_right;
static constexpr uint8_t SERVO_TAIL = SERVO_CHANNELS.tail;

constexpr uint16_t servoChannelMask(uint8_t channel) {
    return channel < 16 ? static_cast<uint16_t>(1u << channel) : 0;
}
static constexpr uint16_t SERVO_ALL_CHANNEL_MASK =
    servoChannelMask(SERVO_FRONT_LEFT) | servoChannelMask(SERVO_FRONT_RIGHT) |
    servoChannelMask(SERVO_REAR_LEFT) | servoChannelMask(SERVO_REAR_RIGHT) |
    servoChannelMask(SERVO_TAIL);
// 单路调试仅允许 home +/- 5 度，不等于装机后的机械安全范围。
static constexpr int SERVO_DEBUG_SPAN_DEGREES = 5;

static constexpr int SERVO_US_MIN = 500;
static constexpr int SERVO_US_MAX = 2500;
static constexpr uint8_t SERVO_STEP_DEGREES = 2;
static constexpr uint32_t SERVO_STEP_DELAY_MS = 12;

struct ServoLimit {
    uint8_t channel;
    int min_angle;
    int max_angle;
    int home_angle;
};

static constexpr ServoLimit SERVO_LIMITS[] = {
    // Array order is body order (fl/fr/rl/rr/tail), NOT physical channel order.
    // These conservative limits are for unloaded bench tests. Calibrate them
    // against the real linkage before increasing the motion range.
    {SERVO_FRONT_LEFT, 70, 110, 90},
    {SERVO_FRONT_RIGHT, 70, 110, 90},
    {SERVO_REAR_LEFT, 70, 110, 90},
    {SERVO_REAR_RIGHT, 70, 110, 90},
    {SERVO_TAIL, 60, 120, 90},
};

static constexpr size_t SERVO_LIMIT_COUNT = sizeof(SERVO_LIMITS) / sizeof(SERVO_LIMITS[0]);
static_assert(SERVO_LIMIT_COUNT == 5, "This robot has exactly five servos");

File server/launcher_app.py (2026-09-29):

"""Visible desktop control surface; no service is started by opening the App."""
from pathlib import Path
import argparse
import json
import os
import queue
import sys
import threading
import tkinter as tk
from tkinter import ttk, messagebox
from launcher_core import Supervisor, read_settings
from launcher_console import ConsoleLogs, SerialConsole
from launcher_imports import show_import
from services.role_config import ROOT
from services.profile_config import list_profiles, load_combination, migrate_legacy


class Launcher:
    def __init__(self, window, root, smoke=False):
        self.window, self.root, self.smoke = window, Path(root), smoke
        self.events = queue.Queue()
        self.busy = self.closing = self.stop_pending = self.poll_pending = False
        self.audio_path = None
        self.destroyed = False
        self.settings = read_settings(root)
        self.logbook = ConsoleLogs(self.root / "server/logs/launcher", lambda s, line: self.events.put(("log", (s, line))))
        self.supervisor = Supervisor(self.settings, self.logbook.supervisor)
        self.serial = SerialConsole(self.logbook.write)
        window.title("PRP 人格 · 音色 · 项目控制台")
        window.geometry("1180x900")
        frame = ttk.Frame(window, padding=10)
        frame.pack(fill="both", expand=True)
        self.state = tk.StringVar(value="服务端实际激活：未确认；下拉框仅表示选择")
        ttk.Label(frame, textvariable=self.state, wraplength=1130).pack(anchor="w")
        pages = ttk.Notebook(frame)
        pages.pack(fill="x", pady=6)
        controls, tests, training = [ttk.Frame(pages, padding=8) for _ in range(3)]
        for page, title in ((controls, "人格与音色"), (tests, "交互测试"), (training, "音色训练")):
            pages.add(page, text=title)
        self.persona = tk.StringVar(value=self.settings.get("default_persona", self.settings.get("default_role", "New_ManBoo")))
        self.voice = tk.StringVar(value=self.settings.get("default_voice", self.settings.get("default_role", "New_ManBoo")))
        self.selectors = []
        self.actions = []
        for label, variable, kind in (("已选择人格提示词", self.persona, "persona"), ("已选择GPT-SoVITS音色", self.voice, "voice")):
            row = ttk.Frame(controls)
            row.pack(fill="x", pady=3)
            ttk.Label(row, text=label, width=25).pack(side="left")
            selector = ttk.Combobox(row, textvariable=variable, state="readonly", width=40)
            selector.pack(side="left", fill="x", expand=True)
            self.selectors.append(selector)
            self.button(row, "新建/导入人格" if kind == "persona" else "导入音色", lambda k=kind: show_import(self, k))
        row = ttk.Frame(controls)
        row.pack(fill="x", pady=5)
        for label, action in (("完整启动", self.start), ("切换人格", self.switch_persona), ("切换音色", self.switch_voice),
                              ("应用组合", self.apply), ("验证选择/显示路径", self.preview),
                              ("健康检查", lambda: self.run(self.supervisor.health))):
            self.button(row, label, action)
        ttk.Button(row, text="停止托管服务", command=self.stop).pack(side="left", padx=3)
        self.details = self.text_area(controls, 8)
        ttk.Label(tests, text="使用服务端实际激活的人格/音色；文字测试不经过ASR或词库命中，不验证ESP32下载、起播动作及后台不重复播放。\n试听仅在电脑播放；完整语音验收需使用ESP32。", wraplength=1100).pack(anchor="w")
        self.input = tk.Text(tests, height=3, wrap="word")
        self.input.pack(fill="x")
        self.input.insert("1.0", "你好，今天过得怎么样？")
        row = ttk.Frame(tests)
        row.pack(fill="x")
        for label, kind in (("人格对话测试", "dialogue"), ("音色试听（生成）", "tts"), ("完整文字链路测试", "chain")):
            self.button(row, label, lambda k=kind: self.test(k))
        ttk.Button(row, text="电脑播放结果", command=self.play).pack(side="left", padx=3)
        ttk.Button(row, text="停止播放", command=self.stop_audio).pack(side="left", padx=3)
        self.test_output = self.text_area(tests, 8)
        ttk.Label(training, text="训练准备：有授权的素材 → 3～10秒切片 → 逐句标注 → 格式化 → SoVITS训练 → GPT训练。\n训练完成后导入成对.ckpt/.pth、参考WAV与逐字原文。这里不会自动训练、覆盖数据或清理模型。\nWebUI地址：http://127.0.0.1:9874/；使用系统外部浏览器。训练日志在新开的可见终端。", wraplength=1100).pack(anchor="w", pady=12)
        row = ttk.Frame(training)
        row.pack(fill="x")
        self.button(row, "启动训练WebUI（可见终端）", lambda: self.run(self.supervisor.start_training))
        ttk.Button(row, text="外部浏览器打开9874", command=self.open_training).pack(side="left", padx=3)
        ttk.Button(row, text="打开数据目录", command=lambda: self.open_path(self.root / "voice_data/manbo")).pack(side="left", padx=3)
        ttk.Button(row, text="打开训练教学", command=lambda: self.open_path(self.root / "docs/项目指南/GPT-SoVITS网页训练教学.md")).pack(side="left", padx=3)
        self.button(row, "导入训练结果", lambda: show_import(self, "voice"))
        serial_row = ttk.LabelFrame(frame, text="ESP32串口（独占；先退出PlatformIO监视器）", padding=5)
        serial_row.pack(fill="x")
        self.com = tk.StringVar()
        self.com_selector = ttk.Combobox(serial_row, textvariable=self.com, state="readonly", width=12)
        self.com_selector.pack(side="left")
        self.button(serial_row, "刷新COM", self.refresh_ports)
        self.button(serial_row, "连接115200", self.connect_serial)
        self.button(serial_row, "断开", lambda: self.run(self.serial.disconnect))
        self.serial_state = tk.StringVar(value="未连接")
        ttk.Label(serial_row, textvariable=self.serial_state).pack(side="left")
        self.command = tk.StringVar()
        ttk.Entry(serial_row, textvariable=self.command).pack(side="left", fill="x", expand=True)
        self.button(serial_row, "发送文本", lambda: self.send_serial(self.command.get()))
        row = ttk.Frame(frame)
        row.pack(fill="x")
        for command in ("status ai bridge", "test audio", "retry wifi", "start machine control", "end machine control"):
            self.button(row, command, lambda c=command: self.send_serial(c))
        log_row = ttk.Frame(frame)
        log_row.pack(fill="x", pady=4)
        ttk.Label(log_row, text="控制台：本机时间 / 来源 / 请求ID；新日志不自动滚动；磁盘日志保留").pack(side="left")
        ttk.Button(log_row, text="清空当前显示（保留文件）", command=self.clear_logs).pack(side="right")
        self.log_tabs = ttk.Notebook(frame)
        self.log_tabs.pack(fill="both", expand=True)
        self.log_widgets = {}
        for source, label in (("summary", "汇总"), ("ollama", "Ollama"), ("gpt_sovits", "GPT-SoVITS"), ("bridge", "AI bridge"), ("serial", "ESP32串口")):
            page = ttk.Frame(self.log_tabs)
            self.log_tabs.add(page, text=label)
            self.log_widgets[source] = self.text_area(page, 12)
        self.refresh_profiles()
        window.protocol("WM_DELETE_WINDOW", self.close)
        window.after(100, self.drain)
        if not smoke:
            window.after(200, self.initialize)
            window.after(3000, self.poll)
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

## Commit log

2026-09-15 feat: trace end-to-end voice latency and preserve project baseline
    [partitions.csv]
2026-09-15 fix: keep ESP32 I2S playback stable
    [bsp_board.cc, main.cc]
2026-09-22 Add PLA five-servo frame V0 fit prototype and hardware dimensions
    [01_main_frame.step, 01_main_frame.stl, 02_battery_cradle.step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]
2026-09-22 Extract standalone hardware reference STEP models
    [00_硬件草模总览_非装配布局.step, 01_SG90_舵机.step, 02_ESP32-S3_开发板.step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]
2026-09-22 docs: 优化论文系统示意图
2026-09-22 docs: 记录论文图示优化
2026-09-22 docs: 精简论文开发过程表述
2026-09-28 feat: configure five servo channels and isolated bench control
    Validate in visible VS Code: PlatformIO build and voice/phrase/servo host regressions passed on 2026-09-29. Includes PWM-off safety dependencies; not flashed or hardware tested.
2026-09-28 docs: confirm firmware runtime and servo-power-off audio baseline
2026-09-29 docs: require complete PowerShell command preflight
2026-09-29 fix: verify launcher bridge identity and packaged source
    [ai_bridge_server.py, launcher_app.py, launcher_core.py]
2026-09-29 docs: trace repetitive replies and phrase cache miss diagnosis
2026-09-29 fix: expire idle dialogue history and expose phrase diagnostics
    [ai_bridge_server.py]
2026-10-08 docs: add defense interaction flow diagram
2026-10-11 docs: verify servo handoff and current hardware evidence
2026-10-11 docs: prepare five-servo calibration record
2026-10-11 docs: refresh board firmware evidence
2026-10-11 docs: index servo calibration handoff
2026-10-11 docs: record unloaded PCA power and audio checks
2026-10-11 docs: record tail servo powered idle check
2026-10-11 docs: record visible acknowledgment and mid-motion PWM stop
